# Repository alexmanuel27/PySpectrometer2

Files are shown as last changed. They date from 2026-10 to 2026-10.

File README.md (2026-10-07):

# System B – Raspberry Pi imaging spectrometer (PySpectrometer2 fork)

Acquisition and processing software for **System B** of the article

> A. M. Rivera-Rivera, D. Martinez-Ortiz, F. Quitin, D. Terwagne, S. C. Nicolis, E. Altshuler, A. Campo,
> *Low-Cost Spectrophotometers: A Comparative Evaluation of Open-Source Architectures* (2026), arXiv:XXXX.XXXXX.

System B is a continuous-spectrum imaging spectrophotometer: a Paton Hawksley pocket spectroscope
(transmission diffraction grating) disperses the light transmitted through a 10 mm cuvette, a
Raspberry Pi camera fitted with a 12 mm M12 lens images the spectrum, and a Raspberry Pi 4B extracts
it with [PySpectrometer2](https://github.com/leswright1977/PySpectrometer2) by **Les Wright**.
A 10 W halogen lamp is used as the light source.

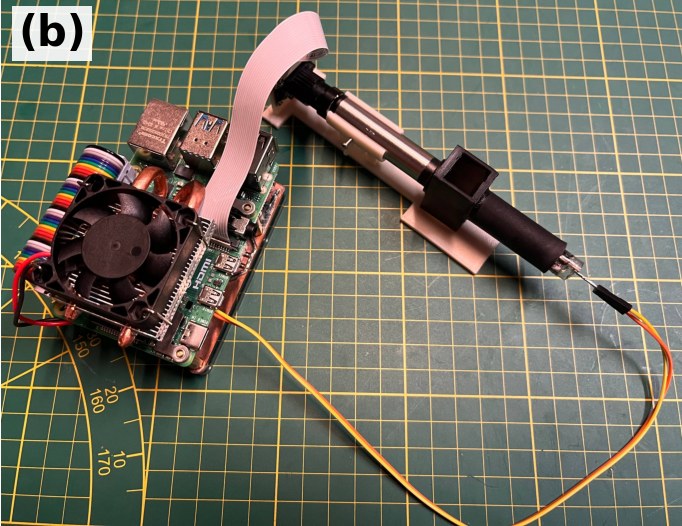
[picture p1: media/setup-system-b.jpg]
System B


*System B: Raspberry Pi camera coupled to a Paton Hawksley pocket spectroscope on a 3D-printed
structure, controlled by a Raspberry Pi 4B (Fig. 1b of the article).*

---

## Relation to the original PySpectrometer2

This repository is a fork of PySpectrometer2 © 2022 Les Wright, distributed under the Apache License 2.0
(see [`LICENCE`](LICENCE) and [`NOTICE`](NOTICE)). The original documentation – key bindings, camera
focusing, USB-camera version – is kept in [`docs/ORIGINAL_README.md`](docs/ORIGINAL_README.md).

What this fork changes with respect to the original:

| | Original PySpectrometer2 | This fork |
|---|---|---|
| Acquisition software (`src/PySpectrometer2-*.py`, `src/specFunctions.py`) | – | **Unmodified** |
| Optical head | Pocket or benchtop spectroscope, M12 zoom or 12 mm lens | Paton Hawksley **pocket** spectroscope + **12 mm** M12 lens, in a 3D-printed mount (`hardware/`) |
| Light source / sample | Emission sources (lamps, lasers) | 10 W halogen lamp through a 10 mm cuvette (absorbance) |
| Absorbance | Not provided | `src/absorbance.py`: absorbance spectrum from a reference and a sample CSV |
| Wavelength calibration | ≥ 3 lines, polynomial fit | 4 mercury lines (404.7, 435.8, 546.1, 577.0 nm), 3rd-order fit |

---

## Repository layout

```
src/        PySpectrometer2 (unmodified) + absorbance.py (added)
hardware/   3D-printable mount and cuvette holder
docs/       Original PySpectrometer2 README
media/      Pictures
```

---

## Bill of materials

Costs as reported in Table IV of the article (EUR, approximate).

| Component | Description | Cost (€) |
|---|---|---:|
| Camera | Raspberry Pi camera with M12 lens mount | 15.00 |
| Single-board computer | Raspberry Pi 4 Model B | 65.00 |
| Lens | 12 mm focal length M12 lens | 15.00 |
| Diffraction grating | [Paton Hawksley Pocket Spectroscope](https://www.patonhawksley.com/product-page/pocket-spectroscope) | 100.00 |
| 3D-printed enclosure + accessories | Spectroscope/lens/camera mount ([`hardware/`](hardware/)) | 10.00 |
| Wiring, PCB, power supply | Pi power supply, camera ribbon cable, wiring | 10.00 |
| | **Total** | **215.00** |

Not included in the total (as in the article): 10 W halogen lamp, 10 mm optical cuvettes, a microSD
card, and a monitor/keyboard (or remote desktop) for the Pi.

---

## Assembly

1. Screw the 12 mm M12 lens onto the camera and connect the camera to the Pi's CSI port.
2. Mount the pocket spectroscope in front of the lens in the 3D-printed holder (`hardware/`), with the
   spectroscope slit facing the cuvette and the halogen lamp behind the cuvette, all on one axis.
3. Start the software (below), point the set-up at a bright source and adjust the lens focus until the
   spectrum is sharp; align the camera so the spectrum is horizontal and centred.
4. Fix all parts rigidly: the wavelength calibration is only valid as long as nothing moves.
5. Measure in darkness.

---

## Installation (Raspberry Pi 4B)

Raspberry Pi OS **Bullseye or later** with the libcamera stack (`picamera2`); the legacy camera
stack is not supported.

```bash
sudo apt update
sudo apt install -y python3-opencv python3-picamera2 python3-numpy git
git clone https://gitlab.com/fablab-ulb/projects/cuban-water-lab/pyspectrometer2.git
cd pyspectrometer2/src
python3 PySpectrometer2-Picam2-v1.0.py            # add --waterfall or --fullscreen if desired
```

`absorbance.py` only needs Python 3 and NumPy and can also be run on any other computer.

---

## Usage

### 1. Wavelength calibration (once per assembly)

1. Point the spectrometer at a fluorescent (mercury) lamp.
2. Press `h` (peak hold), then `p` and click the peaks at **404.7, 435.8, 546.1 and 577.0 nm**, from left to right.
3. Press `c` and type the wavelength of each selected pixel in the terminal. With four points the
   software fits a 3rd-order polynomial and prints R²; the result is stored in `caldata.txt` and reloaded
   at every start.

Full details and screenshots: [`docs/ORIGINAL_README.md`](docs/ORIGINAL_README.md#calibration).

### 2. Acquisition

1. Switch on the halogen lamp and let it stabilise.
2. Insert the cuvette with the **blank** (solvent) and press `s`. This saves `Spectrum-<date>--<time>.csv`
   (plus a PNG) in the working directory. Rename it, e.g. `reference.csv`.
3. Replace the blank with the **sample** without moving anything else and press `s` again; rename the
   file, e.g. `sample.csv`.

### 3. Absorbance spectrum

```bash
python3 absorbance.py reference.csv sample.csv -o sample_absorbance.csv
python3 absorbance.py --selftest      # quick check of the computation
```

---

## Data formats

**`Spectrum-*.csv`** (written by PySpectrometer2):

| Column | Unit | Meaning |
|---|---|---|
| `Wavelength` | nm | Calibrated wavelength of each of the 800 graph columns |
| `Intensity` | a.u. (0–255) | Intensity averaged over 3 sensor rows |

**Output of `absorbance.py`:**

| Column | Unit | Meaning |
|---|---|---|
| `Wavelength_nm` | nm | Reference wavelength grid |
| `I0_Reference` | a.u. | Blank intensity |
| `I_Sample` | a.u. | Sample intensity, interpolated onto the reference grid |
| `Absorbance` | AU | −log₁₀(I / I₀); `nan` where I ≤ 0 or I₀ ≤ 0 |

---

## How to cite

Please cite the article above and the original PySpectrometer2 by Les Wright. Citation metadata is in
[`CITATION.cff`](CITATION.cff).

## Licence

Apache License 2.0 – see [`LICENCE`](LICENCE) and [`NOTICE`](NOTICE). Original work © 2022 Les Wright.

## Acknowledgements

We thank **Les Wright** for PySpectrometer2. This work was carried out within the project *“In situ
monitoring of water quality in Cuban bays: creating and promoting the use of a scientific toolbox”*,
supported by ARES with funding from the Belgian Development Cooperation, at the Innovation Laboratory
(CUJAE, Havana) and Fab Lab ULB (Université libre de Bruxelles). A. C. and S. C. N. acknowledge funding
from the European Union's Horizon Europe research and innovation programme under grant agreement
No. 101181363 (BioDiMoBot). We thank Axel Cornu for valuable advice.

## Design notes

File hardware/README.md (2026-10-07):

# Hardware

Mechanical design files for System B.

| File | Content |
|---|---|
| `support.stl` | 3D-printable vertical support of the optical head (overall size ≈ 35 × 28 × 121 mm) |
| `Body3.stl` | 3D-printable mounting plate for the Pi camera / M12 lens (overall size ≈ 36 × 59 × 17 mm) |

Files in this folder are released under the Apache License 2.0 of the repository.

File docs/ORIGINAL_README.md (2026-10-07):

# PySpectrometer2

The second incarnation of the Spectrometer project!

This is a more advanced, but more flexible version of the original program. It changes the spectrometer from educational 'toy' to serious instrument, which can easily compete with commercial units costing thousands of dollars!

This program, hardware design, and associated information is Open Source (see Licence), but if you have gotten value from these kinds of projects and think they are worth something, please consider donating: https://paypal.me/leslaboratory?locale.x=en_GB
This project is a follow on from: https://github.com/leswright1977/PySpectrometer 

This readme is accompanied by youtube videos, showing how to build and use the spectrometer!
Visit my Youtube Channel at: https://www.youtube.com/leslaboratory

There is a video on this project here: https://youtu.be/SCp9T8NKfnM

## Rationale for the new build

Recent changes in the OS (Bullseye) broke the old version e.g broken video, broken dependencies and so on. PySpectrometer v3.0 was hacked and fixed as of 3.1), however I have been thinking about a rewrite of this software for a while, so here it is!

Accuracy has been significantly improved by implementing multi-wavelength calibration and a Polynomial regression data fit to compute wavelengths as precisely as possible across the measured range.

Tk has been dropped as the GUI to allow easier maintainability, extendability and flexibility. The new interface is coded entirely in OpenCV, and whilst things like trackbars and buttons are now dropped in favour of keybindings, this frees up screen real estate, and allows the support of resizing without fuss, and fullscreen mode is now supported!

In Fullscreen mode on Raspberry Pi systems, the interface is designed to fit 800 x 480 screens, which seem to be a common resolution for RPi LCD's, paving the way for the creation of a stand alone benchtop instrument.



### Whats new:

- Higher resolution (800px wide graph).

- 3 row pixel averaging of sensor data.

- Fullscreen option for the Spectrometer graph.

- 3rd order polynomial fit of calibration data for accurate measurement.

- Improved graph labelling.

- Labelled measurement cursors.

- Optional waterfall display for recording spectra changes over time.

- Key Bindings for all operations.

- Analogue Gain control for the Picam

The functionality of the previous version has been retained, including peak hold, peak detect, Savitsky Golay filter, and the ability to save graphs as png and data as CSV.

A very cool addition to this project is a Waterfall display! This allows the recording of change in in wavelength over time.
For my purposes this is especially useful for Dye Lasers, however this may be of use to those observing the spectra of light sources that may change in intensity or wavelength.

Example waterfall display of a fluorescent lamp:


Waterfall display of a Dye laser being tuned (Coumarin-1). The jagged tuning curve is because this laser was hand-tuned!


Below the tuning curve of Rhodamine 6G


# Hardware

The hardware is simple and widely available and so should be easily to duplicate without critical alignment or difficult construction. The hard work was developing the software.

Resolution/accuracy seems to be down to the nanometre with a well built and calibrated setup, which is excellent for the price of the hardware, especially when you consider the price of commercial components such as the Hamamatsu C12880MA breakout boards which run north of 300 bucks, and has a resolution of 15nm. Of course, this build is physically much larger, but not enormous!

## Standard Spectroscope

For the standard build, I used a pocket spectroscope(link below) coupled into a picamera by means of a zoom lens.
The job is simple: Mount the zoom lens on the picam, and mount the spectroscope in front, and focus the camera on the spectrum, until it is sharp and clear. Use either daylight (which has pronounced Fraunhoffer lines) or a fluorescent lamp, which has pronounced emission lines. The following command will help you: **libcamera-hello -t 0**



The hardware consists of:

- A commercial Diffraction grating Spectroscope https://www.patonhawksley.com/product-page/benchtop-spectroscope

- A Raspberry Pi Camera (with an M12 Thread) https://thepihut.com/products/raspberry-pi-camera-adjustable-focus-5mp

- A CCTV Lens with Zoom (M12 Thread) (Search eBay for F1.6 zoom lens)

Everything is assembled on an aluminium base (note the Camera is not cooled, the heatsink was a conveniently sized piece of aluminium.)





## Miniture Spectroscope

The build is as simple as the standard version, however, uses a miniature pocket spectrometer.



- A commercial Diffraction grating Pocket Spectroscope: https://www.patonhawksley.com/product-page/pocket-spectroscope

- A Raspberry Pi Camera (with an M12 Thread): https://thepihut.com/products/raspberry-pi-camera-adjustable-focus-5mp

- M12x0.5 F2.0 Fixed 12mm Focal length Lens: (search eBay)

## Stand alone unit



Above, a compact unit built with a Hyperpixel 4 inch screen, running on fullscreen mode (800 x 480)

https://shop.pimoroni.com/products/hyperpixel-4?variant=12569539706963

## Custom units

There is nothing to stop you building a spectrometer head with a couple of razor blades, a diffraction grating, a couple of lenses and a Picam! The software should work just the same as shown in this readme!

# User Guide

## Key Bindings:

### Graph Display Controls
* t/g = Analogue Gain up/down (not available on USB version, see below for alternative camera controls)
* o/l = savpoly up/down
* i/k = peak width up/down
* u/j = Label threshold up/down
* h = hold peaks

### Calibration and General Software
* m = measure (Toggles measure function. In this mode a crosshairs is displayed on the Spectrogram that allows the measurement of wavelength)
* p = record pixels (Toggles pixel function (Part of the calibration procedure) allows the selection of multiple pixel positions on the graph)
* x = clear points (Clear selected pixel points above)
* c = calibrate (Enter the calibration routine, requires console input)
* s = save data (Saves Spectrograph as png and CSV data. Saves waterfall as png.
* q = quit (Quit Program)

## Starting the program

First, clone this repo!

In /src you will find:

* PySpectrometer2-Picam2-v1.0.py  (PySpectrometer for Raspberry Pi)
* PySpectrometer2-USB-v1.0.py     (USB version of this program (This is for USB Cameras See end of Readme)).
* specFunctions.py                (A library of functions including: Wavelength to RGB, SavGol filter from Scipy, Peak detect from peakutils, readcal and writecal.

## Dependencies

Run: **sudo apt-get install python3-opencv**

**Also note, this build is designed for Raspberry Pi OS Bullseye, and will only work with the new libcamera based python library (picamera2)**
It will **not** work with older versions of Raspbery Pi OS. You **will** however be able to use PySpectrometer2-USB-v1.0.py with an external USB camera with other Operating Systems.

To run the program, first make it executable by running: **chmod +x PySpectrometer2-Picam2-v1.0.py**

Run by typing: **./PySpectrometer2-Picam2-v1.0.py**

Note to also display the waterfall display, run with the option: **./PySpectrometer2-Picam2-v1.0.py --waterfall**

To run in fullscreen mode (perform calibration in standard mode first), run with the option: **./PySpectrometer2-Picam2-v1.0.py --fullscreen**

When first started, the spectrometer is in an uncalibrated state! You must therefore perform the calibration procedure, but at this stage you should be able to focus and align your camera with your spectroscope using the preview window. Is is expected that red light is on the right, and blue-violet on the left.
An excellent choice for this is daylight, as well defined Fraunhoffer lines are indicative of good camera focus.

## Calibration

This version of the PySpectrometer performs Polynomial curve fitting of the user provided calibration wavelengths. This procedure if done with care with result in a precision instrument!

When light from a diffraction grating falls upon a flat sensor the dispersion of light is not linear, and so calibration with just two data points (as in the old version of this software) will result in inaccurate readings. This nonlinearity is likely compounded by additional nonlinearities introduced by the camera lenses. To address the nonlinearity, the user must provide the pixel positions of at least 3 known wavelengths (4 to 6 is highly recommended for high accuracy!). This information is then used by the program to compute the wavelengths of every single pixel position of the sensor.

Where 3 wavelengths are used for calibration, the software will perform a 2nd order polynomial fit (Reasonably accurate)

Where 4 or more wavelengths are used, the software will perform a 3rd order polynomial fit (Very accurate)

Assuming your physical spectrometer setup is rigid and robust (not held together with gravity, tape or hot glue!), calibration will only need to be done once (Data is saved to a file called: caldata.txt), and therafter when any change is made to the physical setup.

Direct your Spectrometer at a light source with many discrete emission lines. A target illuminated by Lasers would be an excellent (though very expensive!) choice! An inexpensive alternative is a Fluorescent tube.

You should be able to identify several peaks in your graph, now you need to match them up with known good data. For serious work I would recommend an academic resource such as: https://physics.nist.gov/PhysRefData/Handbook/Tables/mercurytable2.htm however in the spirit of citizen science (and because fluorescent lamps are somewhat variable in manufacture), I would recommend this wikipedia article to get you started: https://en.wikipedia.org/wiki/Fluorescent_lamp have a read, and scroll down to the section called: Phosphor composition. In here you will find emission spectra of a variety of fluorescent lamps!

Likely the most useful is this graph: https://commons.wikimedia.org/wiki/File:Fluorescent_lighting_spectrum_peaks_labeled_with_colored_peaks_added.png

These are the notable visible peaks:
* 1 405.4 nm (Mercury) 
* 2 436.6 nm (Mercury)        
* 3 487.7    (Terbium)
* 4 542.4    (Terbium)
* 5 546.5    (Mercury)
* 12 611.6   (Europium)
* 14 631.1   (Europium)

Once you have identified some peaks, at least 3, but even better 4 to 6, first press 'h' to toggle on peak hold, this will stabilize the graph, and even allow you to switch off the light source!

Press the 'p' key on the keyboard. This will toggle on the pixel measuring crosshairs, move the crosshairs to each of your peaks, and click once the crosshairs are aligned with the 'flagpole' of the wavelength marker.
Rinse and repeat for your identified peaks. (Note it makes sense to do this from left to right!)



Once you have selected all of your peaks, press 'c' and turn your attention to the terminal window.
For each pixel number, enter the identified wavelength.



Once you have entered the wavelengths for each data point, the software will recalibrate the graticule and its internal representation of all the wavelength data.
In the console, it will print out the value of R-Squared. This value will give an indication of how well the calculated data matches your input data. The closer this value is to 1, the more accurately you recorded your wavelengths! for example a six nines fit (0.999999xxxx) is excellent, and 5 nines is good. If it is a way off, one or more of your identified wavelengths may be incorrect, and you should repeat the calibaration procedure! (Press 'x' to clear the points, and repeat the calibration procedure)

### Check your work
Refer back to the graph from the wiki, can you identify with a reasonable degree of accuracy other peaks? (bearing in mind your fluorescent lamp may differ from the one on the wiki!).



In the screenshot above above, a well defined peak (not used as a caibration value) at 587.4nm has been detected. Referring to the Wiki this is listed at 587.6nm, only 0.2nm off with a five nines calibration! :-)
For unlabelled peaks, pressing 'm' will toggle on the measurement crosshairs, that display wavelength for any given position.

Calibration data is written to a file (caldata.txt), so calibration is retained when the program is restarted.

# Saving Data

Pressing 's' will save all data. It saves graph and waterfall data as PNG images, with date and time as part of the filename.
Additionally it saves graph data as CSV that can then be opened in other programs such as OpenOffice on the Pi.



# Arbitrary measurement

Pressing the 'm' key will toggle a measurement cursor. This can be used (once the intrument has been calibrated) to arbitratily measure any point on the graph. The following screenshot shows the measurement of a possible Terbium or Mercury line at 577nm



Below: Another example of measurement cursors on a weak line at 437nm. This is from a high pressure Sodium lamp as is in fact likely Mercury (HP Sodium lamps contain Xenon, Mecury and Sodium). 

The prominent peak at 589nm is Sodium.
Of the other peaks: 546.6nm is Mercury, 568.9nm is Sodium, 577nm and 579nm (unlabelled, but just to the left of the 589nm Sodium peak) are both Mercury.



# USB Camera Version

A version of the software is provided for those who wish to use third party USB cameras with the Pi, or even a USB camera with any other Linux box!

The following command line options must be considered:

- Video device number
- Framerate

**Note: the expected resolution from USB cameras is 800x600, other resolutions will cause the software to crash!**

For an external USB camera, first find the device by issuing:
**v4l2-ctl --list-devices**

Once you have determined this, you can run the program. For example if your camera is /dev/video3 and you require a framerate of 15fps you would issue:

**./PySpectrometer2-USB-v1.0.py --device 3 --fps 15**

If you want fine control over camera settings use guvcview: **sudo apt-get install guvcview**

You can run guvcview at the same time as the spectrometer software, so long as you disable guvcview preview, like this:

(assuming your device is /dev/video3)

**guvcview --device /dev/video3 --control_panel**

This will allow you to control:
- Brightness
- Contrast
- Saturation
- Gain
- Other settings (depending on camera, see note below)

Note: Guvcview is a more sensible choice for camera control, than trying to shoehorn in USB camera functionality into this code. The Python OpenCV libary has limited and oftentimes broken support for the huge variety of USB cameras out there, and so direct control with a tried and tested utility makes sense!

# Future work:

It is planned to add inputs of some description, to allow the use of buttons and knobs to control the Spectrometer.

The type of inputs will depend on oddly the type of screen!

The hyperpixel displays consume all of the GPIO on the Pi, however buttons could easily be provided if they talk HID.

DSI displays could be used, however seemingly that might require the user roll back to legacy camera support!

HDMI displays can be used, and this would free up all the GPIO.

A one size fits all approach would be a HID device, there is plenty of choice, including using a Teensy or an Arduino and buttons, or even a number pad with custom keycaps.

I am thinking of implementing something approaching autocalibration, though this might be difficult implement for all use-cases.

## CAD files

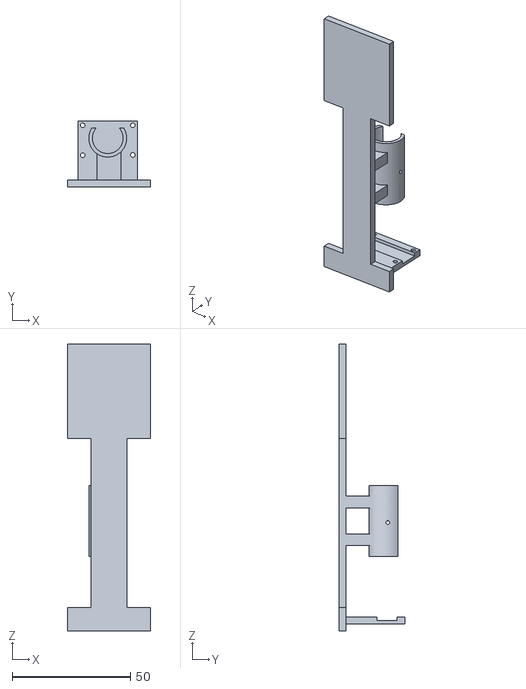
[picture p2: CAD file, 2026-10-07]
hardware/support.stl
35.0 x 28.0 x 121.2

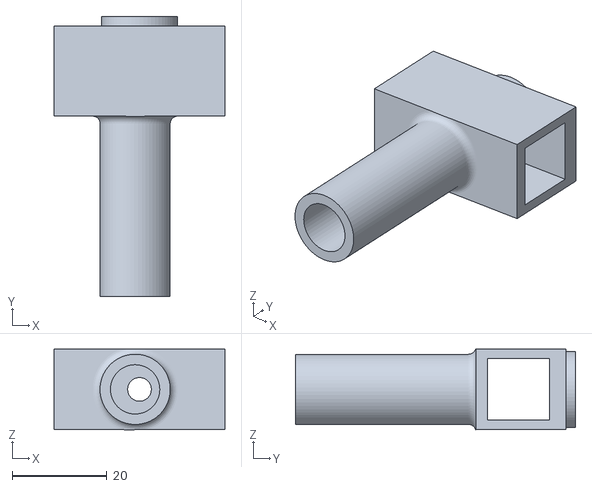
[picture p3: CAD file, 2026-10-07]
hardware/Body3.stl
36.0 x 59.0 x 17.1

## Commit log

2026-10-07 Add absorbance.py: absorbance spectrum from reference and sample CSVs
    Claude-Session: https://claude.ai/code/session_018ENge2Jio4zRB4p7RfLqyn
2026-10-07 Add hardware/ folder for the 3D-printed mount
    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
2026-10-07 New README for System B: changes vs. original, BOM matching Table IV, assembly, install, usage, data formats, citation
    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
2026-10-07 Add System B 3D-printable parts (support and camera plate STLs)
    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
    [Body3.stl, support.stl]
